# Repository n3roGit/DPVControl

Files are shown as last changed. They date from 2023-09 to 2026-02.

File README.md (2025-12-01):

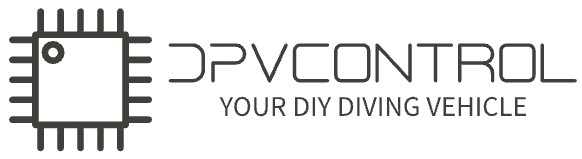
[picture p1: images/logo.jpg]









# THE PROJECT
In this GitHub project, the aim is to build and operate a DPV (Dive Propulsion Vehicle) using standard components. In my case, I will breathe new life into an old Aquazepp. The motor I'm using is a common 2000-watt scooter motor, controlled by a VESC (Vedder Electronic Speed Controller). The entire system is controlled through Reed switches activated by magnets with a Bowden cable.

See the full build process in my [blog](https://3o0.de/gu0).

I would greatly appreciate support for my project. Every $ contributes to enhancing the project.

<a href="https://www.paypal.com/cgi-bin/webscr?cmd=_s-xclick&hosted_button_id=6ZFSVPZWLLAMC">
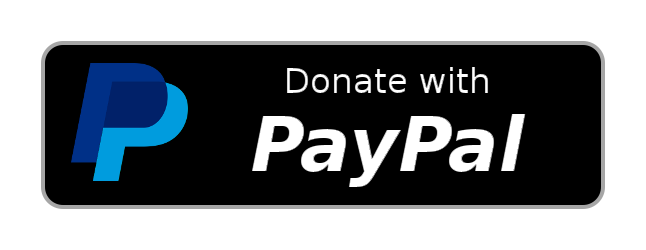
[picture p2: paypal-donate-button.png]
Donate with PayPal
  
</a>

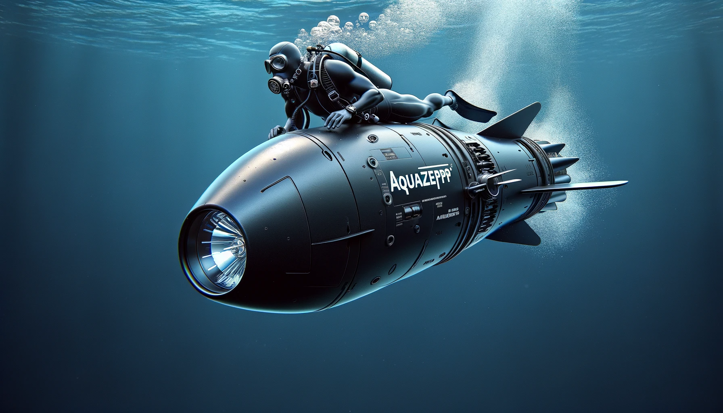
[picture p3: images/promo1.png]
PROMO


# Development

## PlatformIO with VS Code
This project uses **PlatformIO** for development, which provides better dependency management and build system compared to the Arduino IDE.

### Setup Instructions

1. **Install VS Code**: Download from [code.visualstudio.com](https://code.visualstudio.com/)

2. **Install PlatformIO Extension**: 
   - Open VS Code
   - Go to Extensions (Ctrl+Shift+X)
   - Search for "PlatformIO IDE" and install it

3. **Open Project**:
   - Clone this repository
   - Open the project folder in VS Code
   - PlatformIO will automatically detect the `platformio.ini` file

4. **Build and Upload**:
   - Use the PlatformIO toolbar at the bottom of VS Code
   - Click "Build" (✓) to compile
   - Click "Upload" (→) to flash to ESP32
   - Click "Serial Monitor" to view debug output

### Pre-commit Hook for Automated Testing

To ensure code quality, a pre-commit hook is provided that automatically runs all tests before each commit. This prevents commits if any test fails.

**Installation:**
1. Make sure the file `pre-commit.ps1` is located in the project root (it is versioned).
2. In the `.git/hooks/` directory, create a file named `pre-commit.bat` with the following content:
   ```bat
   @echo off
   REM pre-commit hook: runs all PlatformIO tests and prevents commit on failure
   echo Running all tests before commit...
   python -m platformio test -e native
   if errorlevel 1 (
       echo.
       echo ERROR: Some tests failed. Commit aborted!
       exit /b 1
   )
   echo All tests passed. Commit allowed.
   exit /b 0
   ```
3. From now on, all tests will be run automatically before each commit. The commit will be aborted if any test fails.

> **Note:**
> The pre-commit hook only works if you commit from the terminal (CMD). Many GUIs like GitHub Desktop or VSCode-Git do not execute local hooks or do not support batch/shell scripts as hooks.

### Dependencies
All required libraries are automatically managed through `platformio.ini`:
- ArduinoJson, ESP32Servo, OneWire, DallasTemperature
- DHT sensor library, Adafruit NeoPixel
- VescUart, ClickButton, Uptime Library

No manual library installation required!

### Makefile Usage

For a quick command-line workflow, a `Makefile` is provided.  The most common
tasks can be run with:

```bash
make install   # install PlatformIO and Python dependencies
make test      # run unit tests
make build     # build the firmware
make upload    # upload firmware to the ESP32
```

Use `make` without arguments to list all available targets.

# API Documentation

The DPV Control system provides a comprehensive REST API for system monitoring, data retrieval, and configuration management.

📖 **[View API Specification](./api-specification.yaml)** - Complete OpenAPI 3.0 documentation

**Quick Links:**
- **Interactive Documentation:** Open `api-specification.yaml` in [Swagger Editor](https://editor.swagger.io/) or VS Code with OpenAPI extension
- **Base URL:** `http://4.3.2.1` (when connected to DPV WiFi)
- **Format:** JSON REST API

**Available Endpoints:**
- `GET /api/status` - Real-time system status and sensor readings
- `GET /api/data` - Historical sensor data with filtering options
- `GET /api/trip-log` - Complete trip log download
- `GET /api/settings` - Current device configuration
- `POST /api/settings` - Update device settings
- `POST /api/settings/restore` - Restore default settings

**Features:**
- Real-time monitoring of all sensor data
- Historical data retrieval with configurable time ranges
- Complete settings management with validation
- Trip log export functionality
- Session-based data filtering

# Click Codes

| Switch 1 | Switch 2 | Function |
|:---:|:---:|:---:|
| Hold | Hold | Turn motor ON |
| Hold | | Turn motor ON |
| | Hold | Turn motor ON |
| 1 Click  | 1 Click  |  cruise control |
| 1 Click  | | |
| | 1 Click  | |
| 2 Clicks | 2 Clicks | Boost Mode |
| 2 Clicks | | Reactivate |
| | 2 Clicks | Reactivate |
| 2 Clicks | 	 | Stepwise slower |
| | 2 Clicks | Stepwise faster |
| 3 Clicks | 3 Clicks | PowerBank ON/OFF|
| 3 Clicks | | Short light flash |
| | 3 Clicks | Light Level 1, 2, 3, 4, OFF |
| 4 Clicks | 4 Clicks | toggle reverse drive mode (fixed low speed) |
| 4 Clicks | | beep Battery level |
| | 4 Clicks |  |

# Beep Codes
1 = short beep
2= long beep
| Beep | Function | 
|:---:|:---:|
| 12121212 | Leak warning |
|1|still in standby|
|11|going to standby or wake up from standby|
|2|10% battery left|
|22|20% battery left|
|222|30% battery left|
|n*2| Get n beep for every 10% left in battery (beep Battery level)|
|1| once after boot|
|111|No speedup because overloaded|
|1|speed steps exeeded|
|12|Overloaded for too long. Lowering speed.|
|21|No longer overloaded|
|111222111|SOS - Long time without any action. The lamp is also activated with the same code|

# Pinout
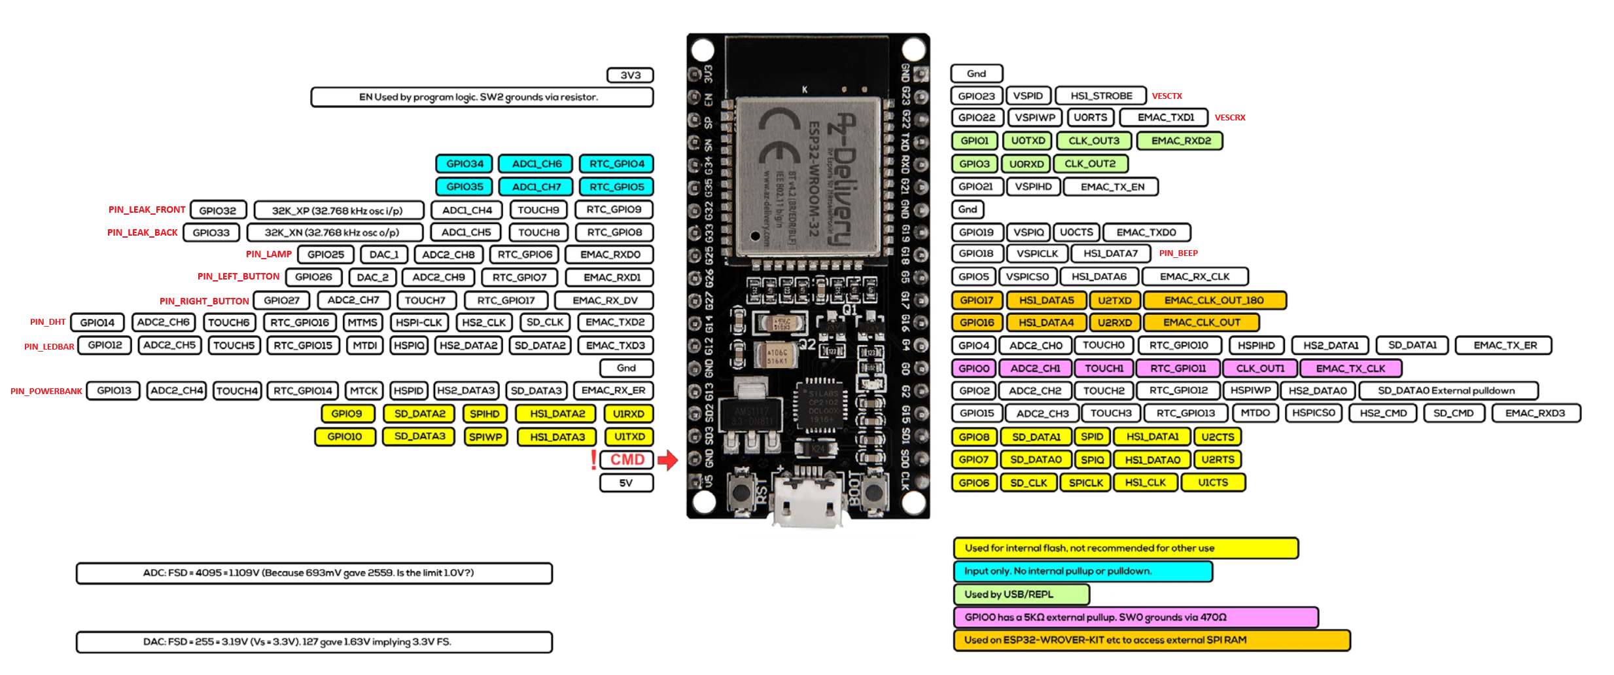
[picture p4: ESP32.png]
ESP32


# Logic
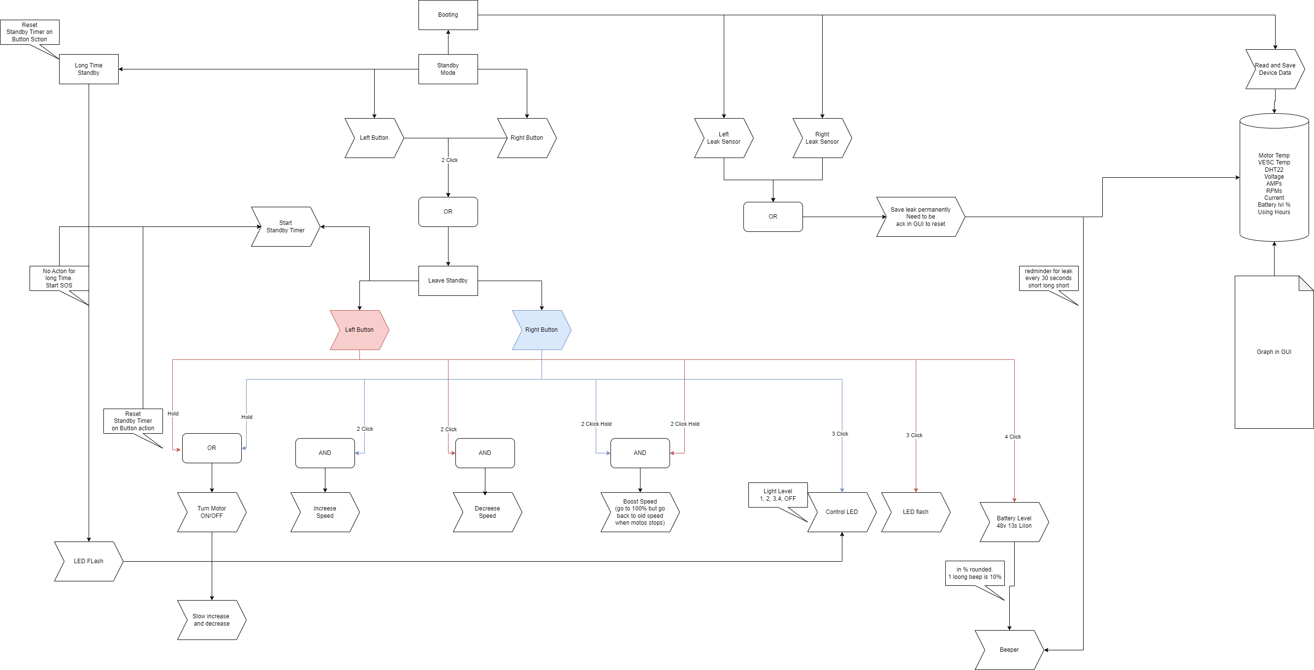
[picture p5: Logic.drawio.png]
logic


# GUI
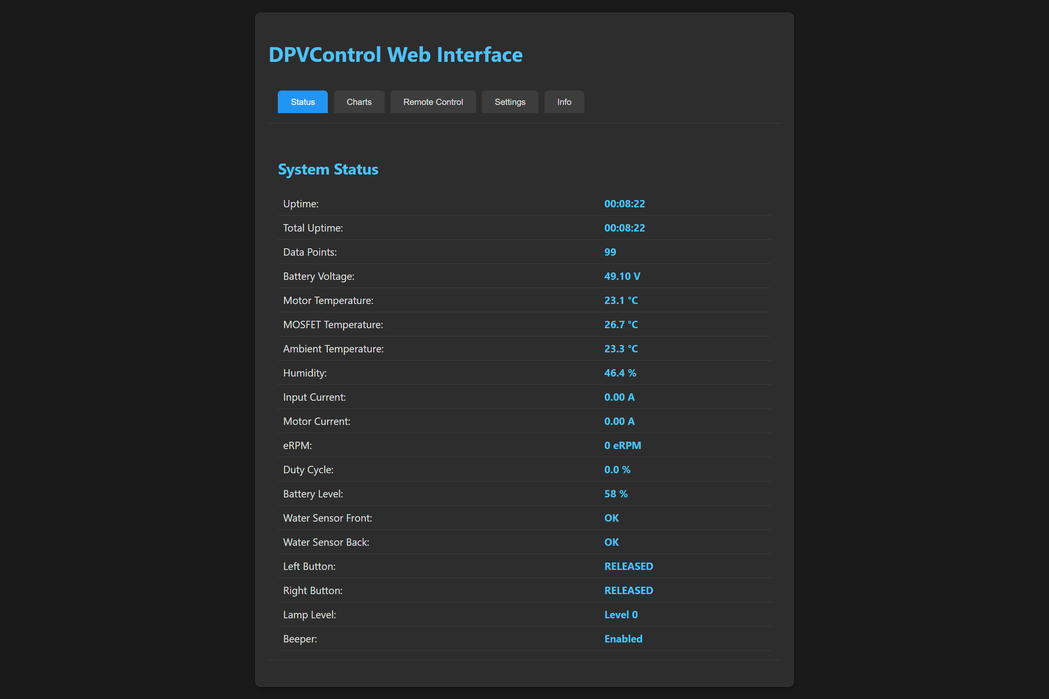
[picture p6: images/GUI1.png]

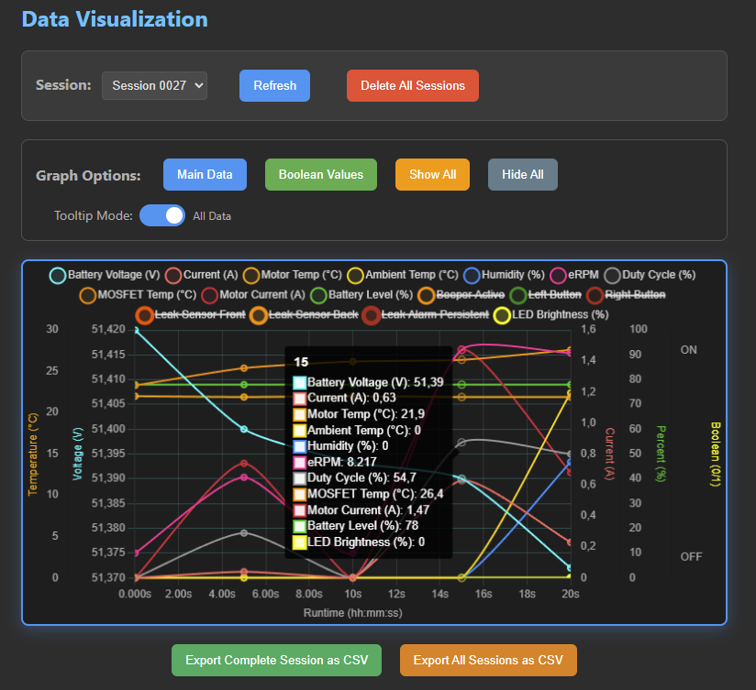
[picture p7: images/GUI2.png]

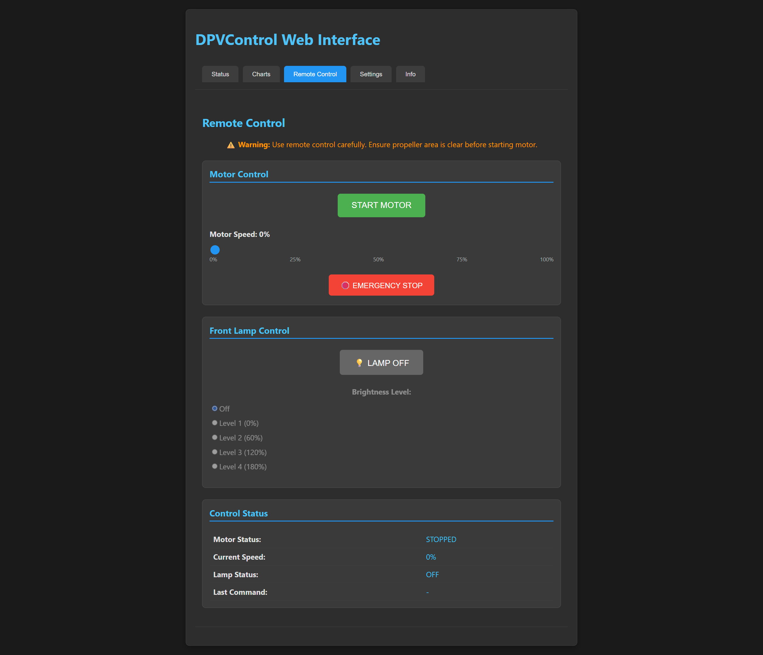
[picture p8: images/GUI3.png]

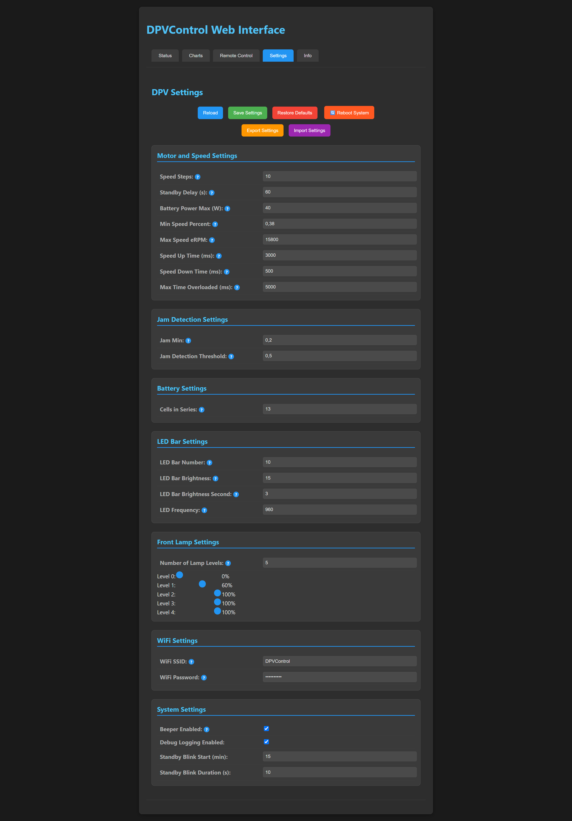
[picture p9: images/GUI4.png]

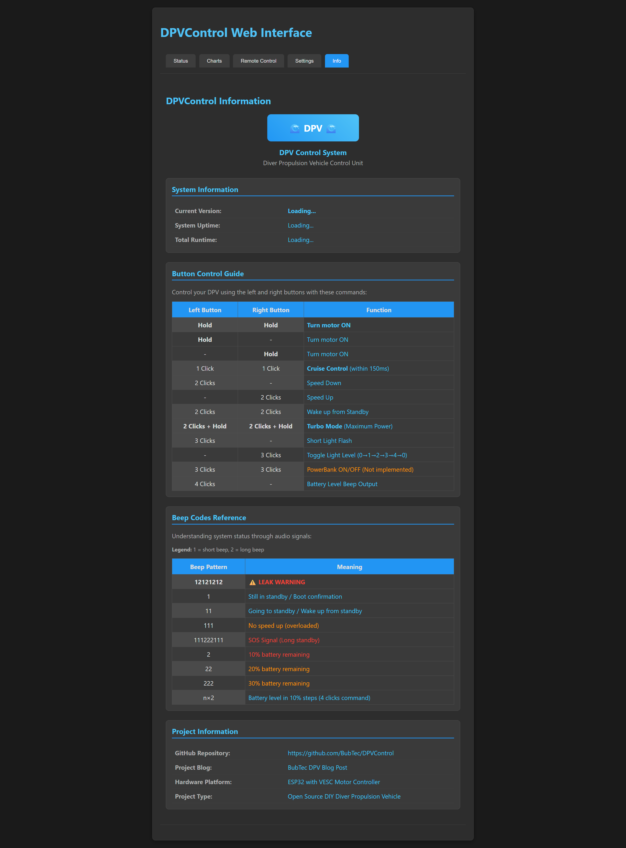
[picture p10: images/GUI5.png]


# Hardware Updates
| Change                                        |
|-----------------------------------------------|
| Handle replaced with POM tube                 |
| Caveline replaced by thin V4A steel cable    |
| Stator integrated to eliminate lateral torque|
| Tow/haul line attached at the top            |
| Impact protection fitted over the magnetic switches|

# Videos
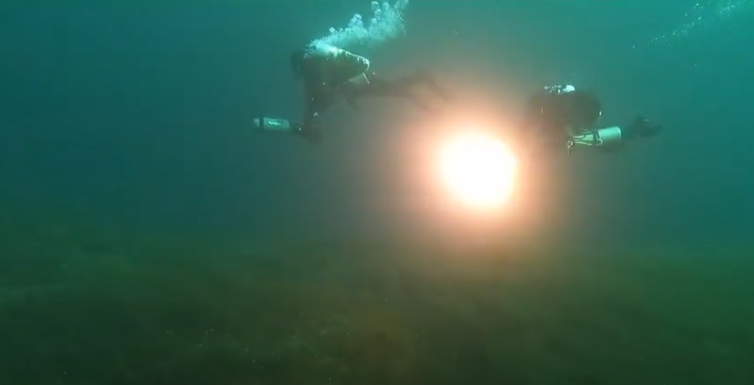
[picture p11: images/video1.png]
[](https://youtu.be/6myfqZKiGTU "Aquazepp first ride")
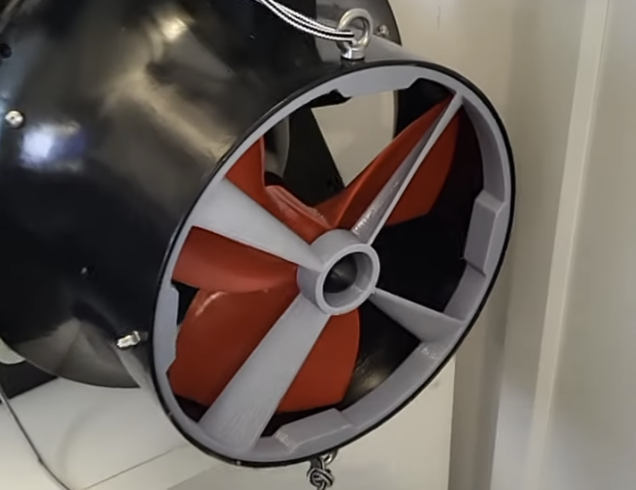
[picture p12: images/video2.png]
[](https://youtube.com/shorts/ZGKomkWQHeM "Aquazepp Stator")
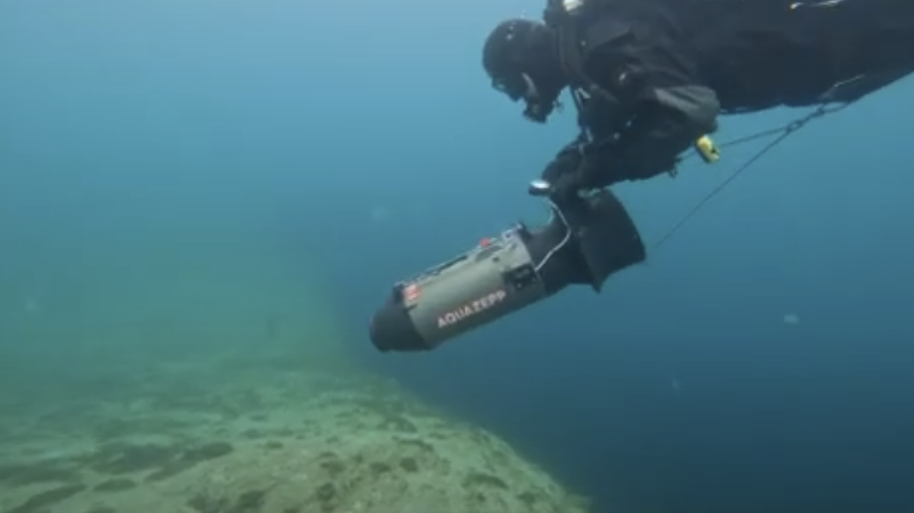
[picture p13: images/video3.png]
[](https://www.youtube.com/watch?v=6m43nQFAH6o "Full speed drive")

# Build Process
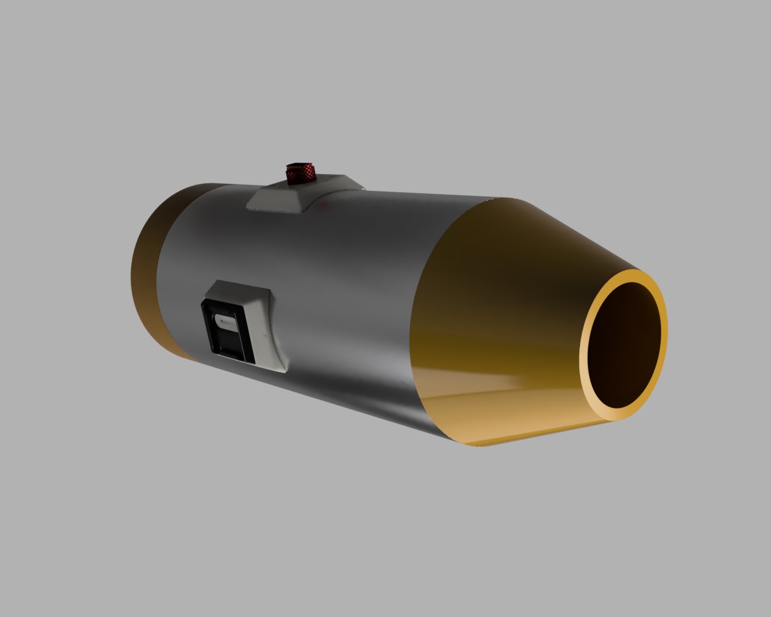
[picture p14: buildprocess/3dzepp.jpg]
Build

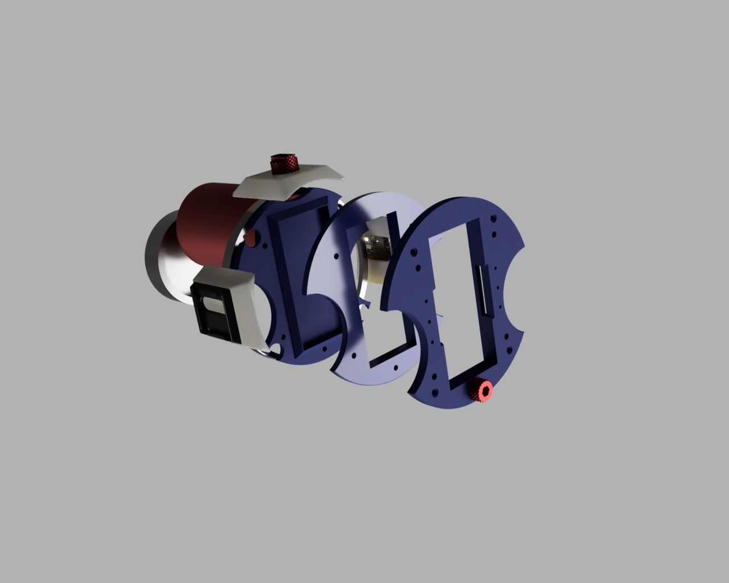
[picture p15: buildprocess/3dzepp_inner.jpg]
Build

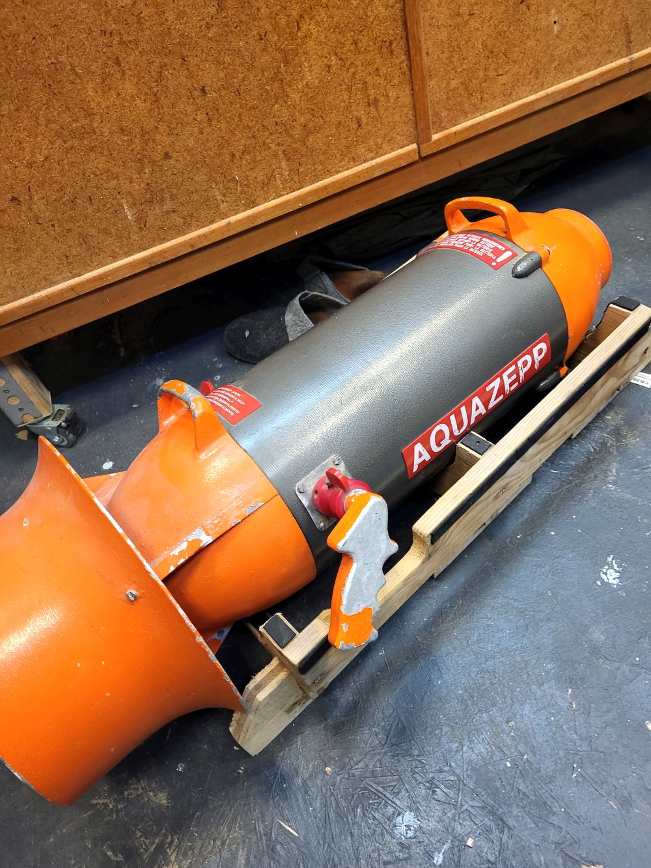
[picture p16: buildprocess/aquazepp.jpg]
Build

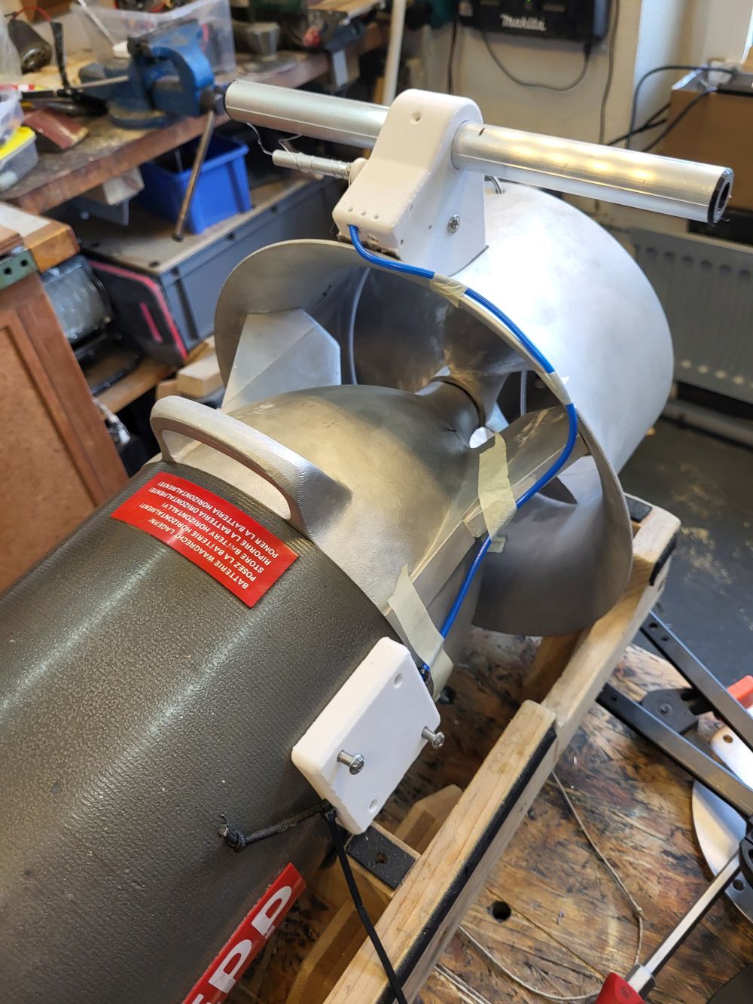
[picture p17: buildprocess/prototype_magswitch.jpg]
Build

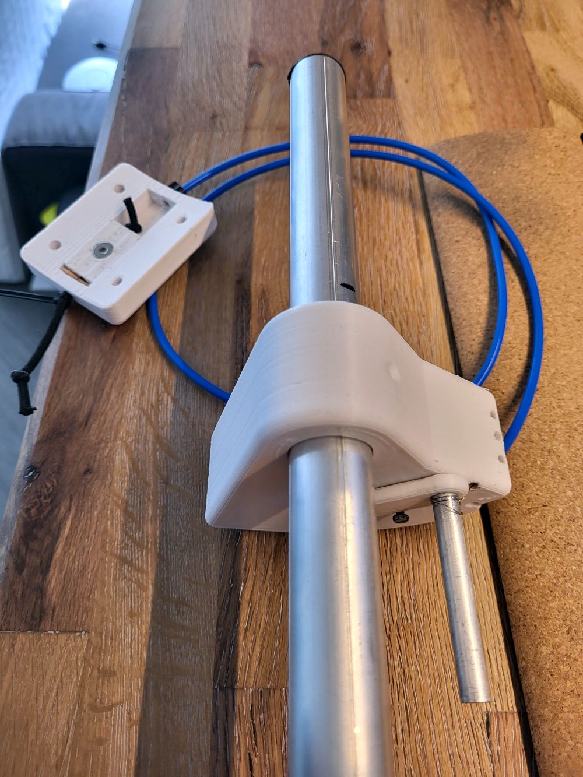
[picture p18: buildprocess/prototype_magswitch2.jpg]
Build

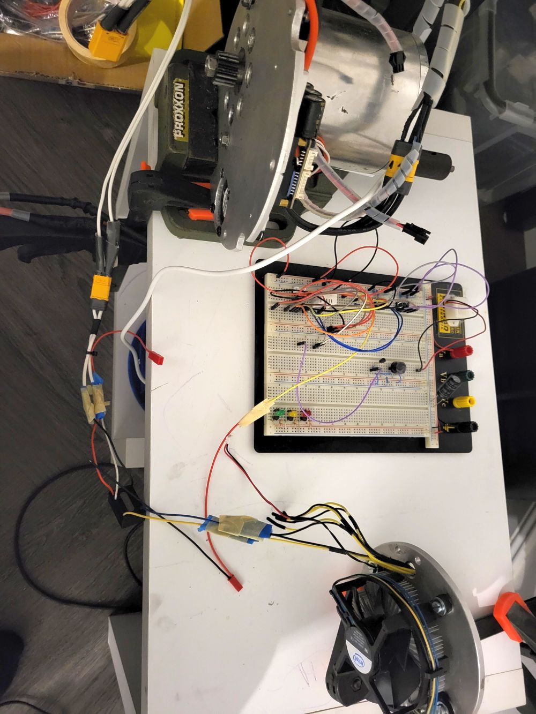
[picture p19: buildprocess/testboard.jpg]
Build

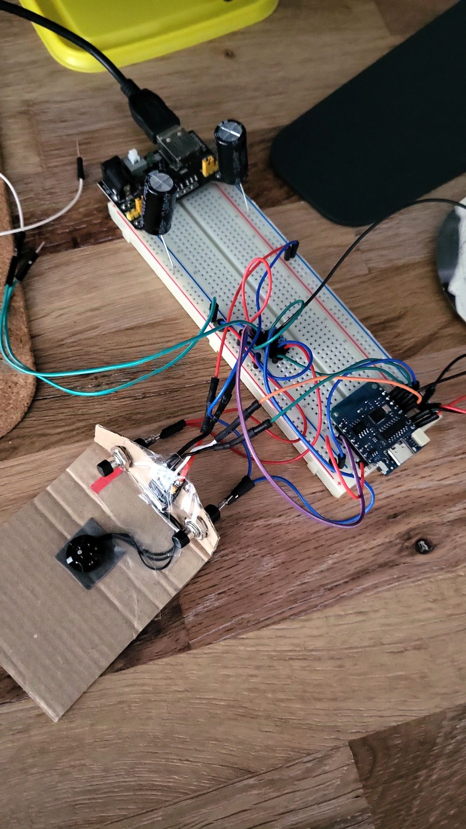
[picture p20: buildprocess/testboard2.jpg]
Build

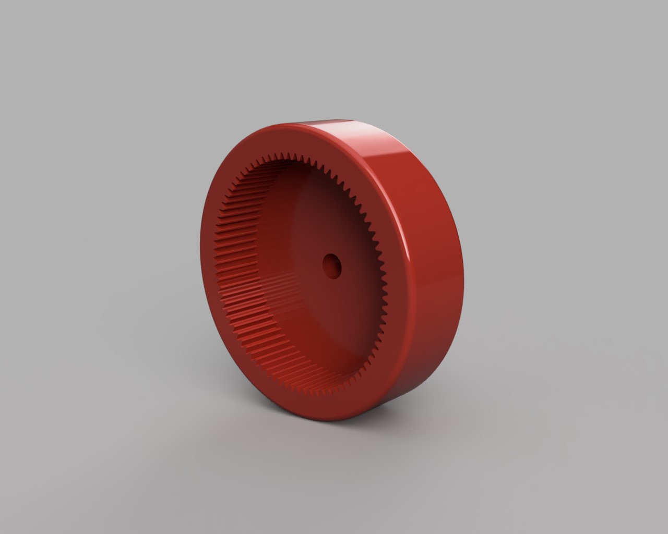
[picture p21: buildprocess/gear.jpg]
Build

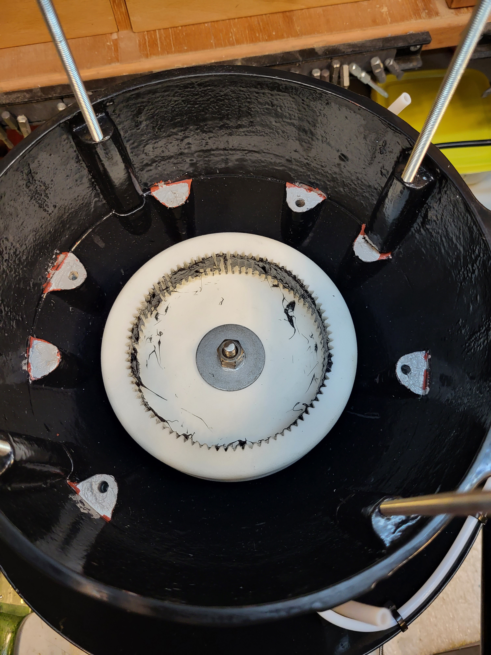
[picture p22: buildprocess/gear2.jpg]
Build

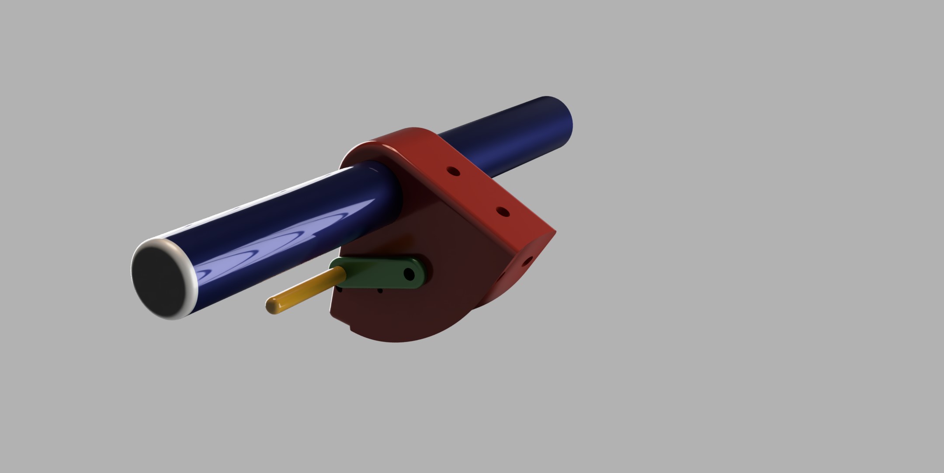
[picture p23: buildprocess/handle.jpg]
Build

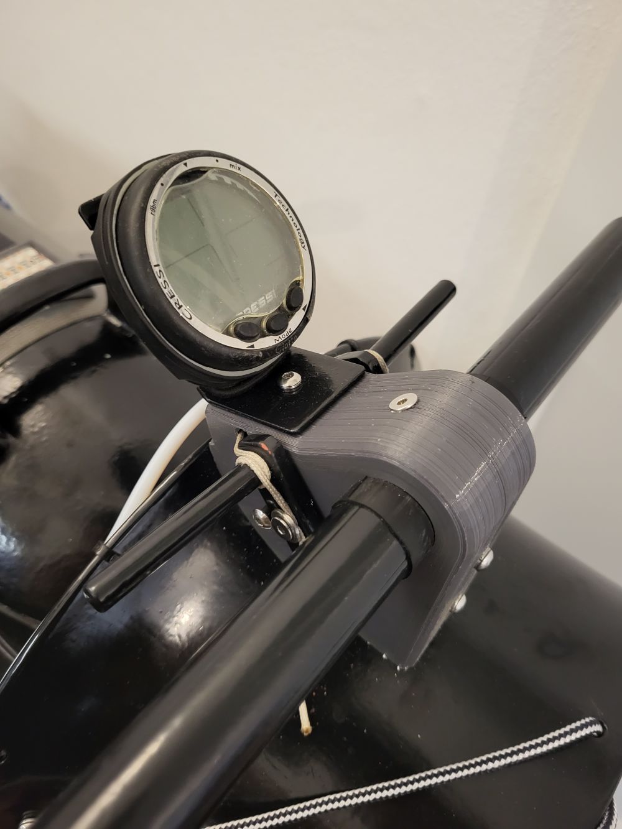
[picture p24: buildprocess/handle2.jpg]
Build

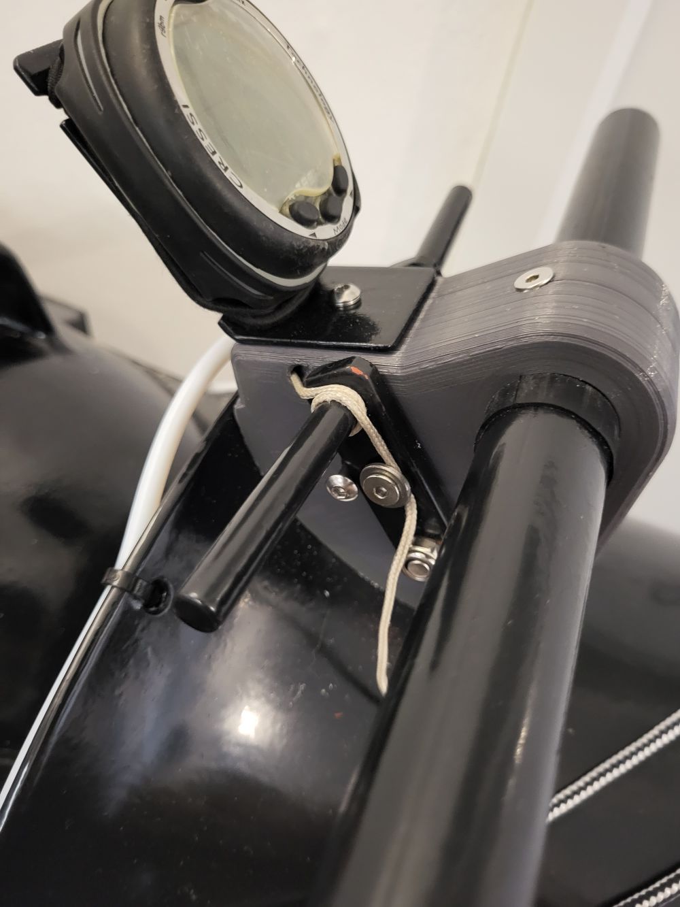
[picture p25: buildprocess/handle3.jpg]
Build

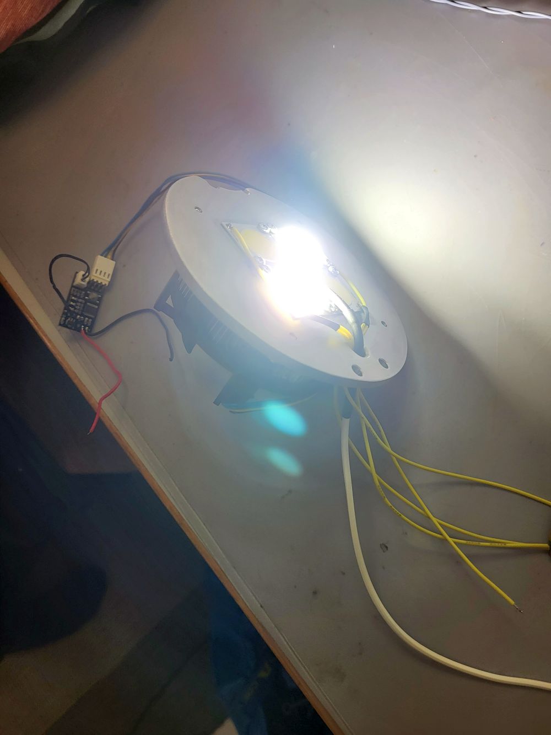
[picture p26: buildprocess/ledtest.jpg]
Build

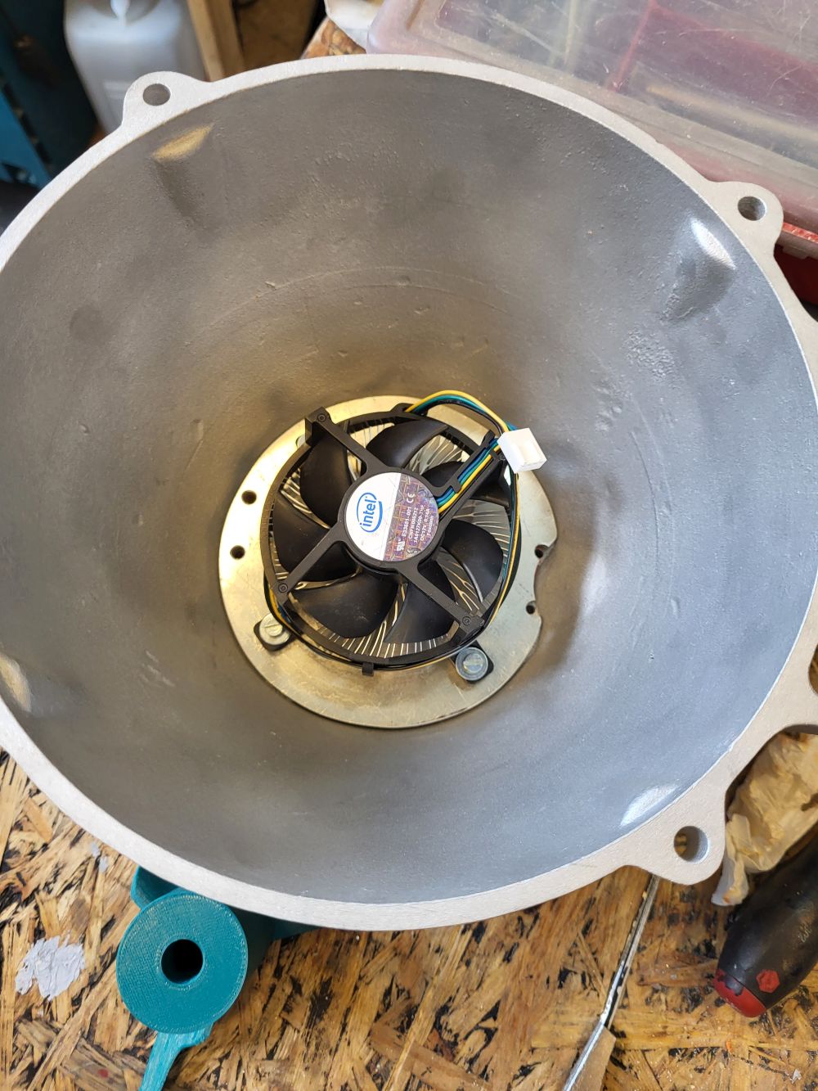
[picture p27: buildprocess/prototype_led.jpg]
Build

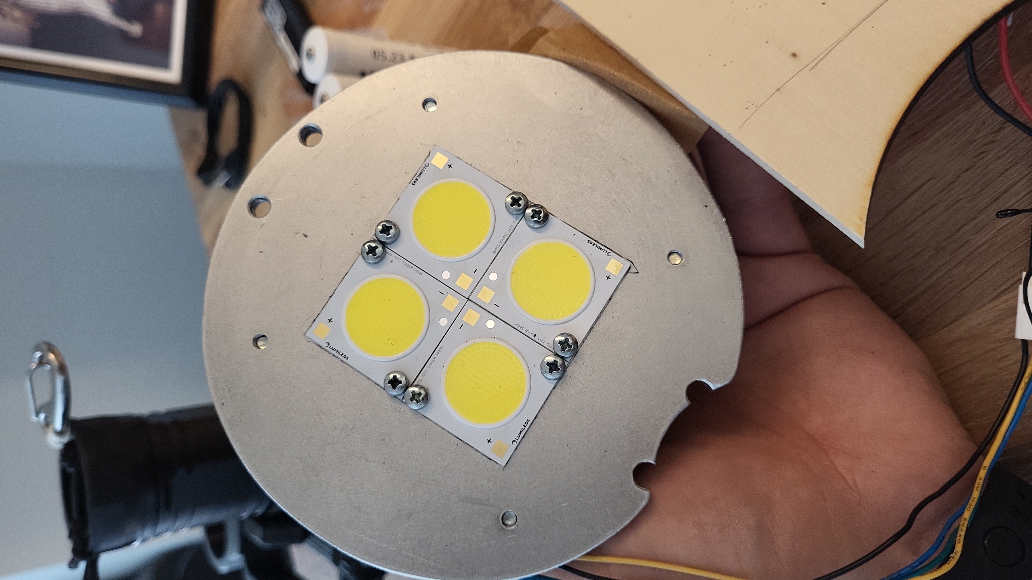
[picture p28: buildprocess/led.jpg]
Build

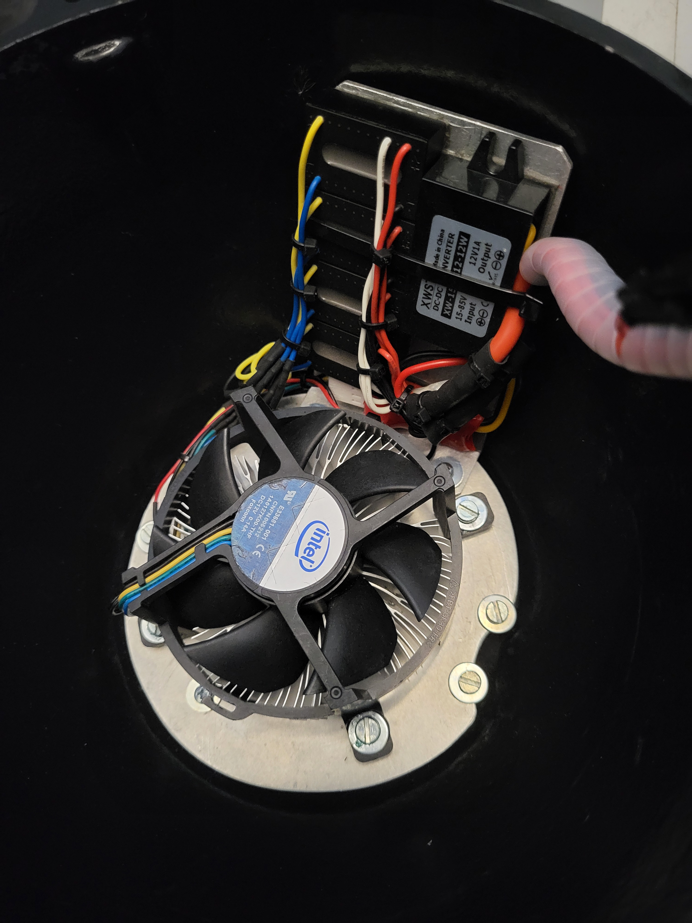
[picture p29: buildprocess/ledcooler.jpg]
Build

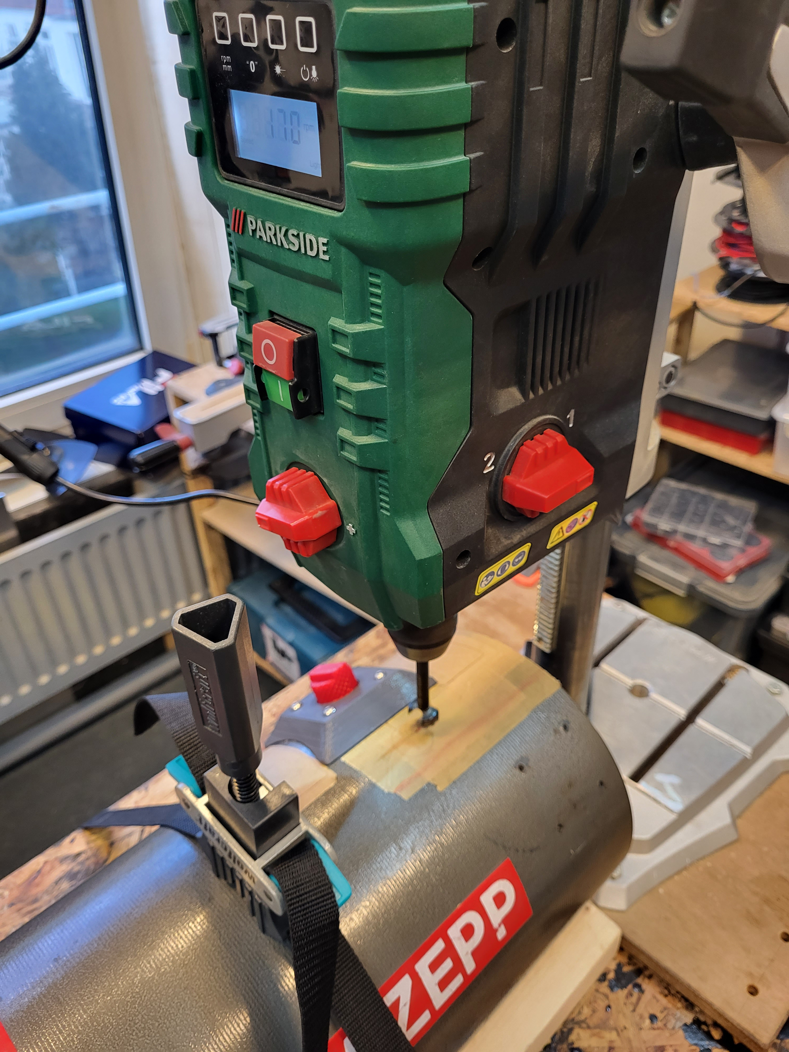
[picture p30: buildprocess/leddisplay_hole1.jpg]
Build

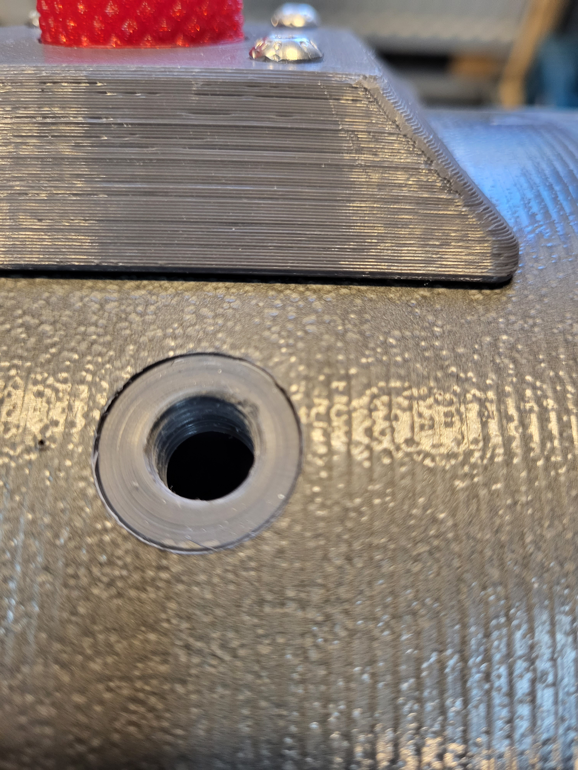
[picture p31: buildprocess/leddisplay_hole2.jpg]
Build

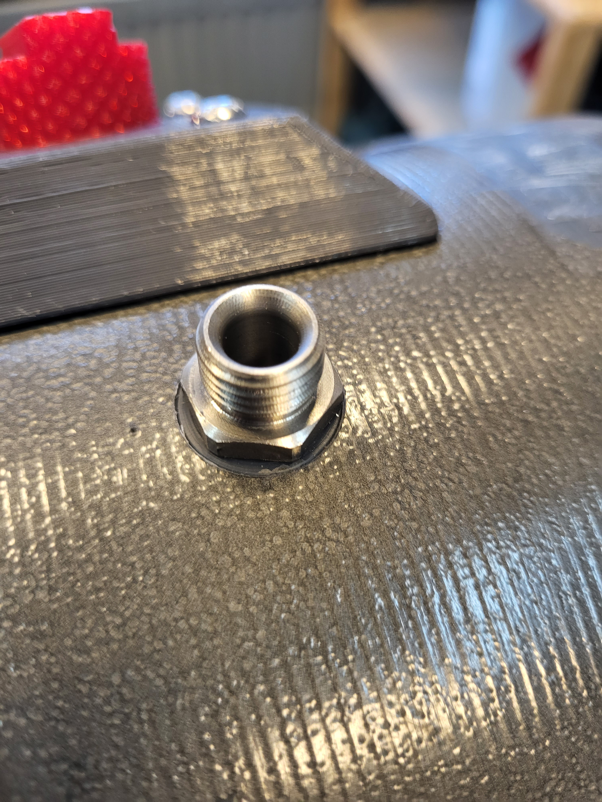
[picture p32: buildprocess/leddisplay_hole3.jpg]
Build

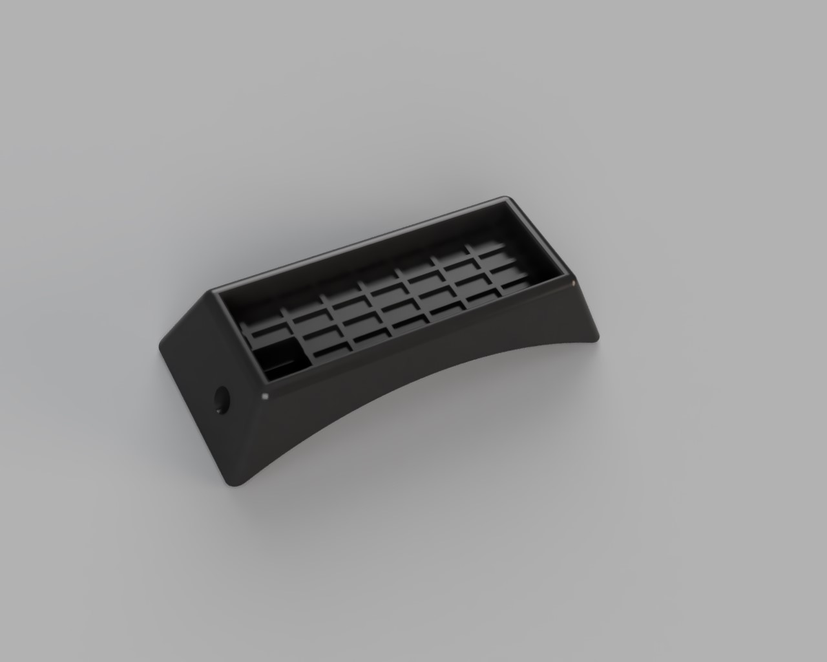
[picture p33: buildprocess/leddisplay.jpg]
Build

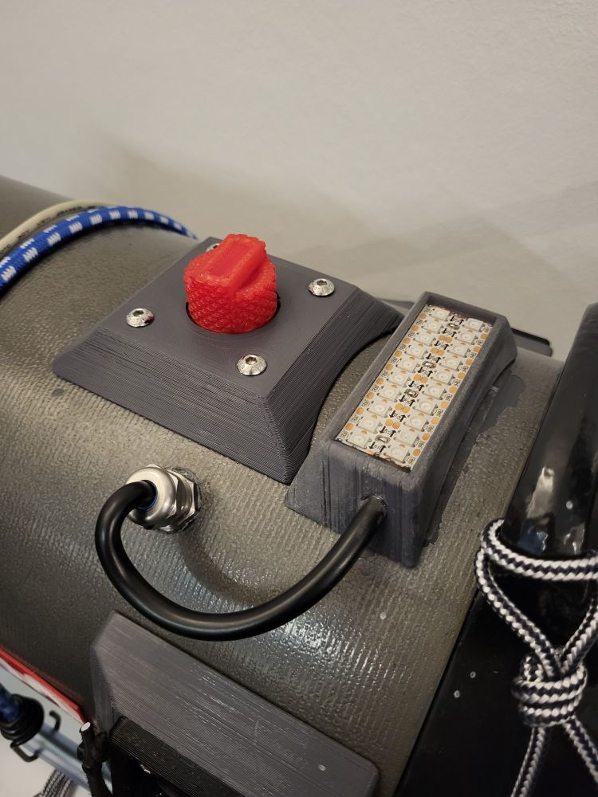
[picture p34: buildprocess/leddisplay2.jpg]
Build

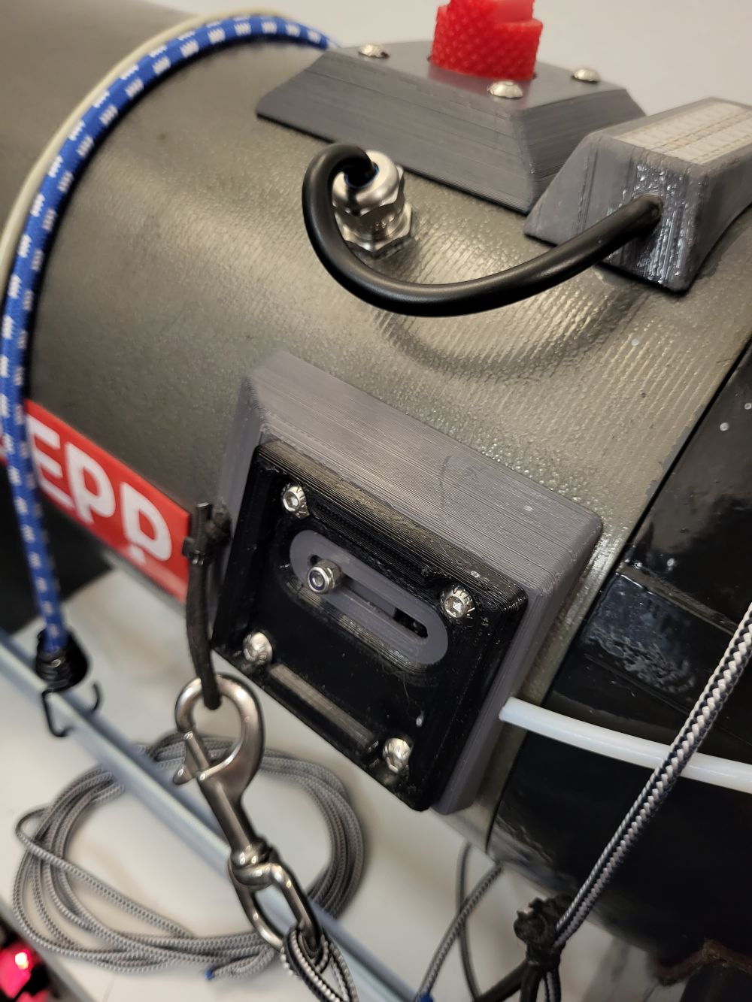
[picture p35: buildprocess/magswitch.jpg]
Build

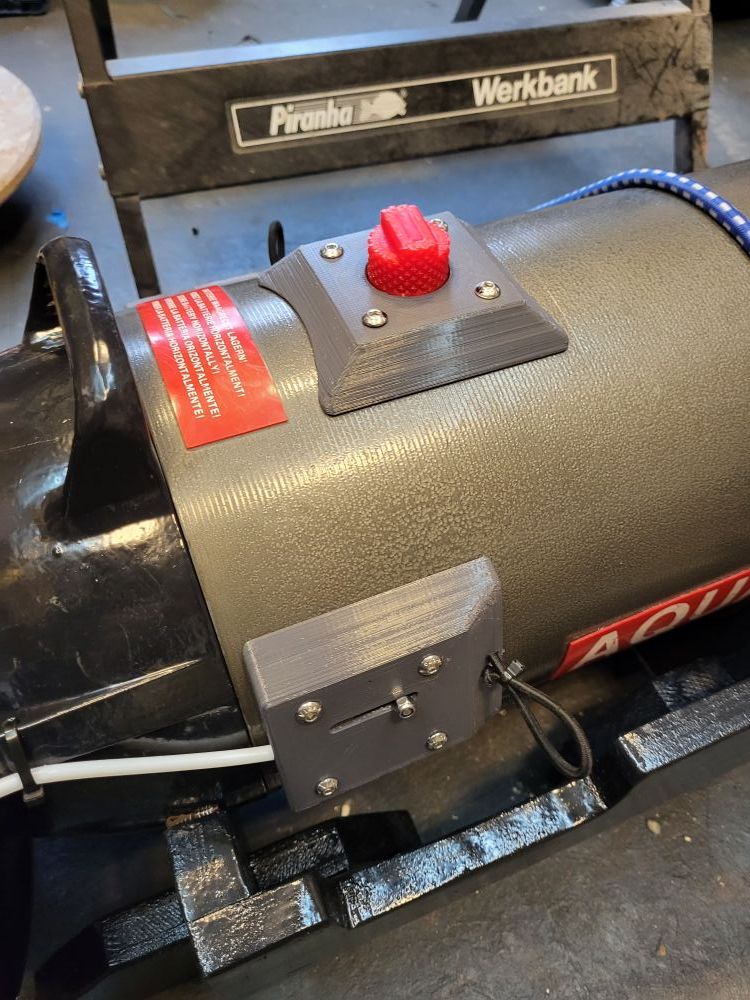
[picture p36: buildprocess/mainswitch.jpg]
Build

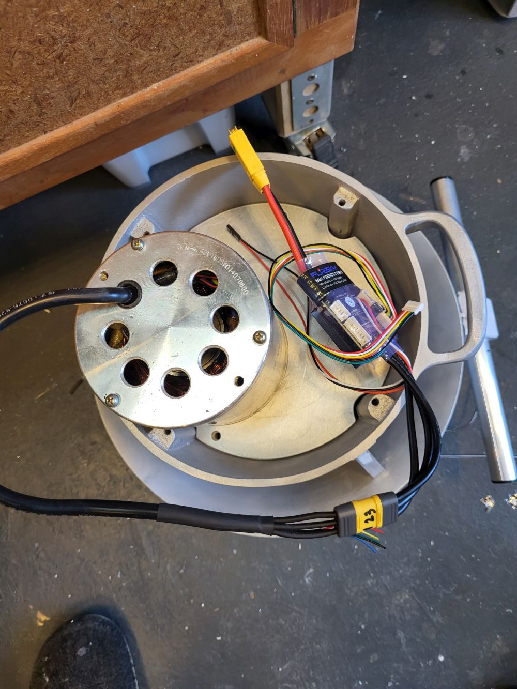
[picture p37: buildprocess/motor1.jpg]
Build

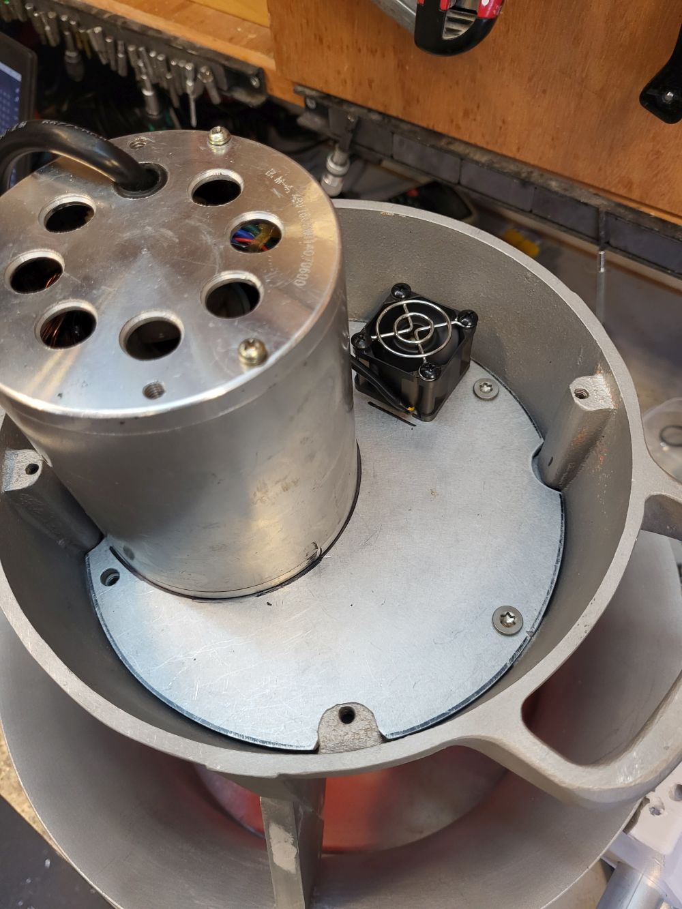
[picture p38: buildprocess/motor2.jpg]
Build

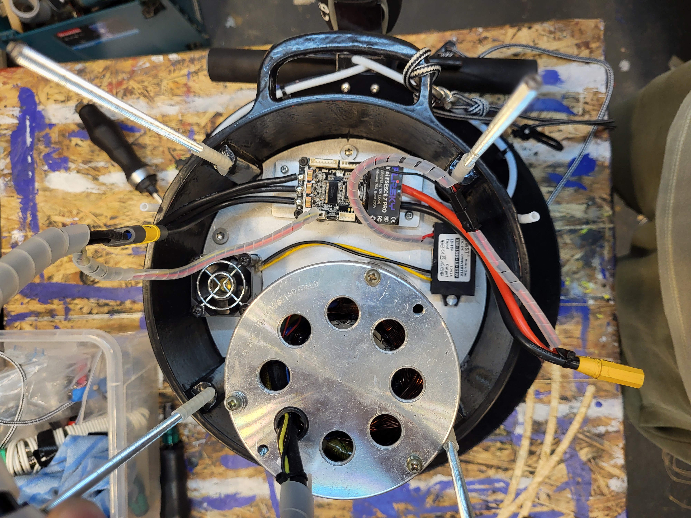
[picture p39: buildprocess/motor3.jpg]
Build

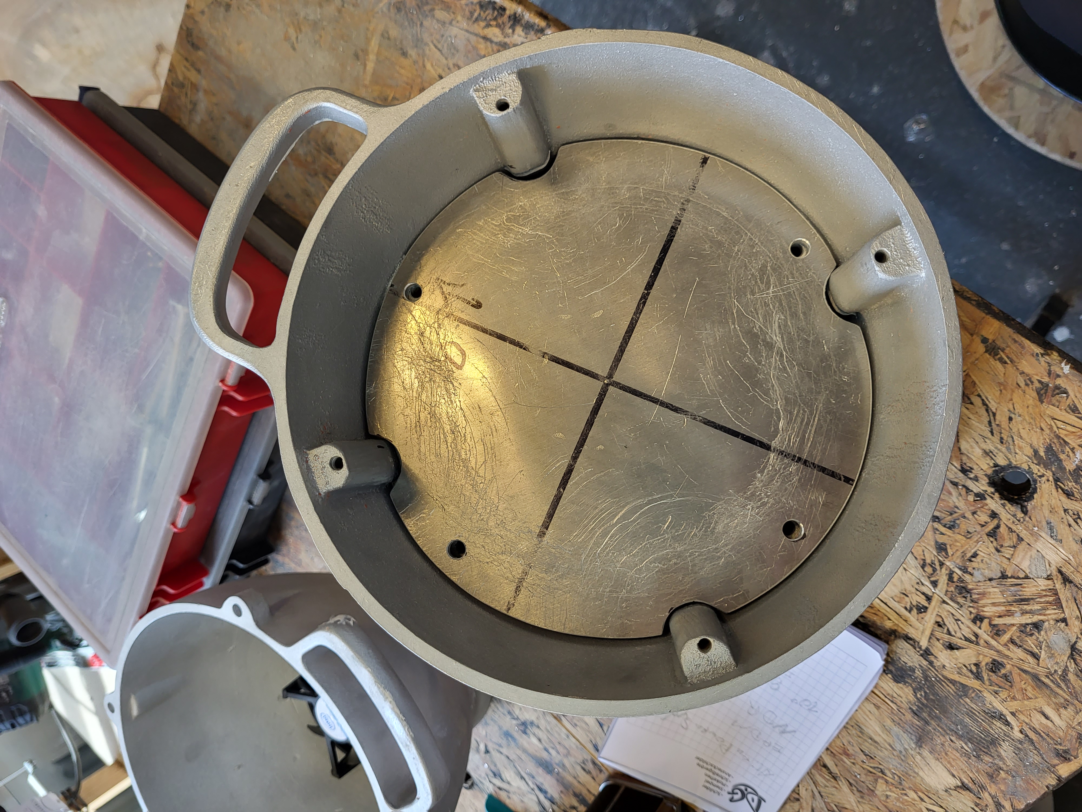
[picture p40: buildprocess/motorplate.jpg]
Build

Build
Build
Build
Build
Build
Build
Build
Build
Build
Build
Build
Build

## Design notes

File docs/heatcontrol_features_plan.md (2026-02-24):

# HeatControl-Features in DPVControl übernehmen

> **GitHub Issues:** Alle Features sind als Issues angelegt. Siehe:
> [#81](https://github.com/BubTec/DPVControl/issues/81) Verzögerter Neustart |
> [#82](https://github.com/BubTec/DPVControl/issues/82) Cache-Control-Header |
> [#83](https://github.com/BubTec/DPVControl/issues/83) Serial Log |
> [#84](https://github.com/BubTec/DPVControl/issues/84) Dynamisches Log-Level |
> [#85](https://github.com/BubTec/DPVControl/issues/85) Erweiterte Captive-URLs |
> [#86](https://github.com/BubTec/DPVControl/issues/86) Serial-Log-Panel |
> [#87](https://github.com/BubTec/DPVControl/issues/87) Client-Zugriffskontrolle |
> [#88](https://github.com/BubTec/DPVControl/issues/88) i18n DE/EN |
> [#90](https://github.com/BubTec/DPVControl/issues/90) HeimNetz + Auto AP |
> [#89](https://github.com/BubTec/DPVControl/issues/89) OTA Update

---

## Übersicht beider Projekte

| Aspekt | HeatControl | DPVControl |
| --- | --- | --- |
| **Plattform** | ESP32-C3 | ESP32 (esp32dev) |
| **Webserver** | AsyncWebServer (ESPAsyncWebServer) | Synchroner WebServer (WiFiServer) |
| **WiFi** | WIFI_AP_STA (AP + HeimNetz/STA) | WIFI_AP (nur AP) |
| **Storage** | EEPROM | LittleFS (JSON) |
| **OTA** | `/update` mit multipart upload | Kein OTA |
| **Serial Log** | Rolling buffer + `/logs` Endpoint  | Nur Serial.print, kein Buffer |
| **AP-Abschaltung** | Auto-Off nach X Min ohne STA | Nicht vorhanden |

---

## 1. Verzögerter Neustart (scheduleRestart) – Risiko 1/10 → [#81](https://github.com/BubTec/DPVControl/issues/81)

**HeatControl:** `scheduleRestart(delayMs)` – Neustart erst nach X ms, damit HTTP-Response vollständig gesendet wird.

**DPVControl:** Sofortiger `ESP.restart()` nach `/api/reboot`; Response könnte abgeschnitten werden.

**Übernahme:** Reboot um 1–2 Sekunden verzögern; in der Zwischenzeit weiterhin Requests bedienen. Globale Variablen `volatile bool restartScheduled`, `volatile unsigned long restartAtMs` – werden vom Webserver (Core 0) gesetzt, von loop() (Core 1) gelesen.

**Risiko: 1/10** – Sehr gering. Verbessert Zuverlässigkeit der Reboot-Response.

---

## 2. Cache-Control-Header – Risiko 1/10 → [#82](https://github.com/BubTec/DPVControl/issues/82)

**HeatControl:** `DefaultHeaders::Instance().addHeader("Cache-Control", "no-cache, no-store, must-revalidate")` für alle Responses.

**DPVControl:** Teilweise Cache-Header; nicht einheitlich.

**Übernahme:** Bei allen API-Responses und HTML-Seiten konsistent `Cache-Control: no-cache` setzen.

**Risiko: 1/10** – Sehr gering. Reine Header-Ergänzung.

---

## 3. Serial Log – Risiko 2/10 → [#83](https://github.com/BubTec/DPVControl/issues/83)

**HeatControl:** Rolling-Buffer (`serialLogBuffer[12001]`), `appendLineToRollingBuffer()` in logic_helpers.cpp, alle `logLine()`/`logf()` schreiben zusätzlich in den Buffer, Endpoint `/logs` liefert Buffer als text/plain.

**DPVControl:** [log.cpp](../src/log.cpp) nutzt nur `Serial.print()`; kein Buffer, kein Log-Endpoint.

**Übernahme:**

- Rolling-Buffer-Funktion portieren (ohne HeatControl-spezifische Abhängigkeiten) oder vereinfachte Variante in DPVControl implementieren
- **Mutex** für Buffer-Zugriff (log() wird von Core 0 und Core 1 aufgerufen – webserver, vesc, datalog, main loop)
- `log()` in [log.cpp](../src/log.cpp) erweitern: zusätzlich in Buffer schreiben
- Neuer API-Endpoint `/api/logs` (GET) – liefert Buffer als text/plain
- [api-specification.yaml](../api-specification.yaml) und Web-UI anpassen (z.B. Log-Tab oder -Modal)

**Risiko: 2/10** – Gering. Mutex erforderlich wegen Multi-Core-Zugriff.

---

## 4. Dynamisches Log-Level (setLogLevel) – Risiko 2/10 → [#84](https://github.com/BubTec/DPVControl/issues/84)

**HeatControl:** Log-Level (Error/Info/Debug) per POST `/setLogLevel` umschaltbar, persistent in EEPROM.

**DPVControl:** `debugLoggingEnabled` (boolean) in Settings, nur über Settings-API änderbar.

**Übernahme:** Entweder `debugLoggingEnabled` beibehalten oder dreistufiges Log-Level einführen. Neuer Endpoint `/api/log-level` (GET/POST) oder Erweiterung von Settings.

**Web-UI:** Dropdown/Select (Error/Info/Debug) in Settings oder im Serial-Log-Panel (Feature 6); Speichern-Button.

**Risiko: 2/10** – Gering. Bestehende Logik anpassen; Debug-Logging könnte Performance beeinträchtigen.

---

## 5. Erweiterte Captive-Portal-URLs – Risiko 2/10 → [#85](https://github.com/BubTec/DPVControl/issues/85)

**HeatControl:** Zusätzliche Handler: `/gen_204`, `/fwlink`, `/library/test/success.html`, `/connecttest.txt.gz`, etc. Plus `CaptiveRequestHandler` für unbekannte Hosts.

**DPVControl:** Hat bereits `/generate_204`, `/ncsi.txt`, `/hotspot-detect.html`, etc. Fehlt u.a. `/gen_204`, `/fwlink`, einige Varianten.

**Übernahme:** Fehlende Pfade ergänzen; ggf. Host-basierte Redirect-Logik nachbilden.

**Risiko: 2/10** – Gering. Nur zusätzliche Redirect-Pfade; Verbesserung der Captive-Portal-Erkennung.

---

## 6. Serial-Log-Panel in der Web-UI – Risiko 2/10 → [#86](https://github.com/BubTec/DPVControl/issues/86)

**HeatControl:** Eigenes Panel mit Log-Level-Dropdown, Auto-Scroll, periodischem Abruf von `/logs`.

**DPVControl:** Kein Log-Panel.

**Übernahme:** Nach Implementierung von Serial Log (Feature 3) ein Log-Panel/Modal in der Web-UI einbauen – analog HeatControl. **Abhängigkeit:** Feature 3 muss zuerst implementiert sein.

**Web-UI:** Log-Anzeige (pre/textarea), Log-Level-Dropdown, Auto-Scroll, Aktualisieren-Button.

**Risiko: 2/10** – Gering. Abhängig von Feature 3; nur Frontend.

---

## 7. Client-Zugriffskontrolle (isAllowedWebClient) – Risiko 3/10 → [#87](https://github.com/BubTec/DPVControl/issues/87)

**HeatControl:** Schreibende Endpoints (POST/PUT) prüfen Client-IP. Erlaubt: 4.3.2.x (AP), 10.x, 172.16–31.x, 192.168.x. Andere IPs erhalten 403 Forbidden.

**DPVControl:** Keine Zugriffskontrolle – jeder im AP kann alle Endpoints nutzen.

**Übernahme:** Vor schreibenden API-Handlern Client-IP prüfen; bei ungültiger IP 403 zurückgeben. DPVControl nutzt `client.remoteIP()` – analog implementierbar.

**Risiko: 3/10** – Gering. Nur zusätzliche Prüfung; falsche Konfiguration könnte legitime Clients blockieren.

---

## 8. Mehrsprachigkeit (i18n DE/EN) – Risiko 4/10 → [#88](https://github.com/BubTec/DPVControl/issues/88)

**HeatControl:** Vollständige Übersetzung in der Web-UI (data-i18n, `t()`-Funktion, langToggleBtn). DE/EN wechselbar.

**DPVControl:** Web-UI nur auf Englisch (bzw. gemischt).

**Übernahme:** i18n-Objekt mit Keys, `t(key)`-Funktion, data-i18n-Attribute, Sprachumschalter. Relativ viel UI-Arbeit.

**Web-UI:** Sprachumschalter-Button (DE/EN); alle Texte mit data-i18n versehen.

**Risiko: 4/10** – Mittel. Kein Funktionsrisiko, aber viele Strings; fehlende Keys zeigen Key-Namen.

---

## 9. HeimNetz + Auto AP Abschaltung – Risiko 5/10 → [#90](https://github.com/BubTec/DPVControl/issues/90)

**HeatControl:**

- WIFI_AP_STA: AP und STA gleichzeitig
- STA verbindet sich mit HeimNetz (activeSsid/activePassword)
- Wenn STA verbunden und AP nicht manuell aktiviert → AP wird abgeschaltet
- `apAutoOffMinutes`: Wenn nach X Minuten kein STA → AP aus, WiFi komplett aus

**DPVControl:**

- Nur AP; `wifiSSID`/`wifiPassword` sind AP-Credentials
- Keine STA-Verbindung, kein Auto-Off

**Übernahme:**

- **Neue Settings:** `staSSID`, `staPassword` (HeimNetz), `apAutoOffMinutes` (0 = deaktiviert)
- **AP-Credentials:** Bleiben `wifiSSID`/`wifiPassword` (oder umbenennen zu `apSSID`/`apPassword` für Klarheit)
- **WiFi-Start:** `WiFi.mode(WIFI_AP_STA)` wenn STA-Credentials gesetzt, sonst weiterhin nur AP
- **STA-Connect:** `WiFi.begin(staSSID, staPassword)` im Setup
- **Loop-Logik (wie HeatControl):**
  - Wenn STA verbunden und AP nicht manuell aktiviert → `WiFi.softAPdisconnect()`, `WiFi.mode(WIFI_STA)` → **primär über HeimNetz erreichbar**
  - Wenn `apAutoOffMinutes > 0` und kein STA nach Timeout → AP aus, ggf. WiFi komplett aus
- **API:** Settings um neue Felder erweitern; optional `/api/wifi` oder ähnlich für Status (STA verbunden, AP an/aus)
- **Web-UI:** Neue WLAN-Sektion mit Eingabefeldern (HeimNetz-SSID, HeimNetz-Passwort, AP-SSID, AP-Passwort, AP Auto-Off in Min), Speichern-Button; Status-Anzeige (STA verbunden?, AP aktiv?, IP-Adressen)

**Architektur-Anpassung:** DPVControl macht WiFi-Setup aktuell in `webserverTask`. Für WIFI_AP_STA und handleWifiLifetime in loop() empfohlen: WiFi-Setup in `setup()` vor `setupWebserver()` verschieben (analog HeatControl). Task übernimmt nur server.begin() und Request-Loop.

**Risiko: 5/10** – Mittelhoch. WiFi-Verhalten ändert sich; Captive Portal und DNS müssen weiterhin korrekt funktionieren. Gründlich testen.

---

## 10. Auto Update – Risiko 8/10 → [#89](https://github.com/BubTec/DPVControl/issues/89)

**HeatControl:**

- AsyncWebServer mit multipart-Upload-Callback
- `/update` GET: HTML-Formular
- `/update` POST (multipart): Chunkweiser Upload, `Update.begin()`, `Update.write()`, `Update.end()`
- Web-UI: GitHub-Release-Check, Download firmware.bin, POST an `/update`

**DPVControl:**

- Synchroner WebServer; kein nativer multipart-Upload-Handler
- Kein OTA-Endpoint

**Entscheidung:** OTA auf dem bestehenden sync WebServer (Option B). Kein Wechsel zu AsyncWebServer – der aktuelle WebServer funktioniert zuverlässig. Multipart-Parsing per `client.read()` in Chunks, direkt an `Update.write()`.

**Übernahme:**

- `/update` GET: Einfache HTML-Seite mit File-Input (analog HeatControl)
- `/update` POST: Multipart-Parsing im sync WebServer, `Update`-API nutzen
- **Web-UI:** Buttons „Update prüfen“, „Auto-Update“, „Update-Seite öffnen“; Update-Banner bei neuer Version (analog HeatControl)
- **Firmware-URL:** GitHub-Release `BubTec/DPVControl` (analog HeatControl mit BubTec/HeatControl)

**Risiko: 8/10** – Hoch. OTA-Fehler können Brick verursachen. Mindestgröße prüfen, nur .bin akzeptieren, Tests mit Mock.

---

## Zusammenfassung: Risiko-Matrix (sortiert gering → hoch)

| # | Feature | Issue | Risiko | Kurzbeschreibung |
| --- | --- | ----- | --- | --- |
| 1 | Verzögerter Neustart | #81 | 1 | scheduleRestart(delayMs) |
| 2 | Cache-Control-Header | #82 | 1 | Konsistente No-Cache-Header |
| 3 | Serial Log | #83 | 2 | Rolling-Buffer + /api/logs |
| 4 | Dynamisches Log-Level | #84 | 2 | Error/Info/Debug umschaltbar |
| 5 | Erweiterte Captive-URLs  | #85 | 2 | gen_204, fwlink, etc. |
| 6 | Serial-Log-Panel (UI) | #86 | 2 | Log-Anzeige in Web-UI |
| 7 | Client-Zugriffskontrolle | #87 | 3 | 403 für nicht-lokale IPs |
| 8 | i18n DE/EN | #88 | 4 | Mehrsprachige Web-UI |
| 9 | HeimNetz + Auto AP | #90 | 5 | WIFI_AP_STA, STA-Credentials, Auto-Off |
| 10  | Auto Update | #89 | 8 | OTA multipart, Brick-Risiko |

---

## Empfohlene Reihenfolge (nach Risiko)

**Phase 1 – Risiko 1–2 (Features 1–6):**

1. Verzögerter Neustart (#81)
2. Cache-Control-Header (#82)
3. Serial Log (#83)
4. Dynamisches Log-Level (#84)
5. Erweiterte Captive-URLs (#85)
6. Serial-Log-Panel in Web-UI (#86)

**Phase 2 – Risiko 3–5 (Features 7–9):**

7. Client-Zugriffskontrolle (#87)
8. i18n DE/EN (#88) – optional, Aufwand relativ hoch
9. HeimNetz + Auto AP (#90)

**Phase 3 – Risiko 8 (Feature 10):**

10. Auto Update (#89) – zuletzt, gründlich testen

---

## Feature-Abhängigkeiten

| Feature | Issue | Abhängigkeiten | Hinweis |
| --- | ----- | --- | --- |
| 1. Verzögerter Neustart | #81 | keine | |
| 2. Cache-Control-Header | #82 | keine | |
| 3. Serial Log | #83 | keine | Backend-Basis für Feature 6 |
| 4. Dynamisches Log-Level | #84 | keine | Kann mit Feature 6 kombiniert werden |
| 5. Erweiterte Captive-URLs  | #85 | keine | |
| 6. Serial-Log-Panel | #86 | **#83** (Serial Log) | Braucht `/api/logs` Endpoint |
| 7. Client-Zugriffskontrolle | #87 | keine | |
| 8. i18n DE/EN | #88 | keine | |
| 9. HeimNetz + Auto AP | #90 | keine | Benötigt eigene WLAN-Sektion in Settings |
| 10. Auto Update | #89 | keine | |

**Reihenfolge bei Abhängigkeiten:** #86 erst nach #83 implementieren.

---

## Tiefenanalyse: Risiken, Abhängigkeiten und Konfliktstellen

### 1. Threading und Concurrency (Core 0 vs. Core 1)

| Komponente | Core | Aufrufer von log() |
| --- | ---- | --- |
| main loop() | 1 | buttonLoop, motorLoop, checkForLeak, logVehicleState, etc. |
| webserverTask | 0 | handleClient → alle API-Handler |
| vescTask | 0 | VESC-Kommunikation, battery updates |
| datalogger task | 0 | datalogLoop |

**Kritisch – Serial Log (#83):** `log()` wird von **beiden Cores** aufgerufen. Der Rolling-Buffer (`serialLogBuffer`) wird damit **concurrent** beschrieben. Ohne Synchronisation: Datenraces, korrupter Buffer.

**Lösung:** Mutex (xSemaphoreCreateMutex) um `appendLineToRollingBuffer()`; alternativ portMUX für kurze kritische Sektion.

**Kritisch – scheduleRestart (#81):** `restartScheduled` und `restartAtMs` werden vom Webserver (Core 0) gesetzt, von `loop()` (Core 1) gelesen. **Lösung:** `volatile` oder atomare Zugriffe.

### 2. WiFi-Architektur: DPVControl vs. HeatControl

| Aspekt | HeatControl | DPVControl |
| --- | --- | --- |
| WiFi-Setup  | In `setup()` vor setupWebServer | **In webserverTask** (nach Task-Start) |
| Reihenfolge | setup() → WiFi → setupWebServer | setup() → setupWebserver() → Task startet → WiFi in Task |

**Problem bei #90 (HeimNetz + Auto AP):** In DPVControl macht `webserverTask` den kompletten WiFi-Setup. Für WIFI_AP_STA brauchen wir:

- `WiFi.onEvent()` für staConnected
- `handleWifiLifetime()` in `loop()` (Core 1) – ruft `WiFi.softAPdisconnect()` auf

**Lösung:** WiFi-Setup in `setup()` vor `setupWebserver()` verschieben; Task übernimmt nur `server.begin()` und Request-Loop.

### 3. Konflikt-Matrix

| Feature A | Feature B | Konflikt |
| --- | --- | --- |
| 3 (Serial Log) | 4 (Log-Level) | Keiner – Feature 4 steuert, was Feature 3 puffert |
| 3 (Serial Log) | 6 (Log-Panel) | Keiner – 6 nutzt 3 |
| 9 (HeimNetz) | 5 (Captive-URLs) | Wenn AP aus: Captive-Portal nicht mehr relevant (nur STA) |
| 9 (HeimNetz) | 7 (Zugriffskontrolle) | isAllowedWebClient muss STA-IP (192.168.x) erlauben – bereits in 10.x, 172.16–31.x, 192.168.x |
| 1 (scheduleRestart) | 10 (OTA) | Nach OTA: Reboot. scheduleRestart verzögert – OTA sollte eigenes Reboot nach Update.end() nutzen |

### 4. Offene Punkte (entschieden)

1. **AsyncWebServer vs. sync WebServer für OTA:** Der bestehende sync WebServer kann OTA mit manuellem Multipart-Parsing. **OTA auf dem bestehenden WebServer** (Option B). Multipart-Parsing per `client.read()` in Chunks, direkt an `Update.write()`.
2. **HeimNetz-Priorität:** Wenn STA verbunden und AP nicht manuell aktiviert → AP wird abgeschaltet. **Primär über HeimNetz erreichbar**.
3. **Firmware-URL für Auto-Update:** GitHub-Release-URL fest auf `BubTec/DPVControl`.

---

## Weitere Dokumentation

- [feature_issues_to_create.md](feature_issues_to_create.md) – Manuelle Issue-Vorlagen (falls GitHub CLI nicht verfügbar)
- [.cursor/rules](../.cursor/rules) – Projektregeln für Implementierung

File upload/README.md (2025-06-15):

# Embedded Web Files System

This directory contains web files that are automatically embedded into the ESP32 firmware during compilation.

## How it works

1. **Pre-Build Process**: Before each compilation, the `embed_webfiles.py` script automatically:
   - Scans all files in this `/upload` directory
   - Converts them to C++ header files with PROGMEM data
   - Generates a registry system for the webserver
   - Places all generated files in `src/generated/` (ignored by git)

2. **Runtime**: The webserver serves files directly from embedded memory, eliminating the need for SPIFFS/LittleFS uploads

## Benefits

✅ **No Data Loss**: Web file updates no longer overwrite persistent ESP32 data (dive logs, settings, uptime)
✅ **Automatic**: Files are embedded during every build - no manual upload required
✅ **Faster**: Files are served from program memory instead of filesystem
✅ **Reliable**: No filesystem corruption issues
✅ **Version Control**: Web files are properly tracked in git

## File Structure

Place your web files directly in this directory:
- `index.html` - Main interface
- `style.css` - Styling
- `app.js` - JavaScript functionality
- `*.html` - Additional pages (settings, info, remote)
- `*.js` - JavaScript libraries
- `*.jpg`, `*.png` - Images
- Any other web assets

## Development Workflow

### Making Changes to Web Files

1. **Edit files** in this `/upload` directory
2. **Compile** normally: `python -m platformio run -e esp32dev`
3. **Upload** firmware: `python -m platformio run -e esp32dev -t upload`

The embedding happens automatically during compilation!

### File Size Considerations

- **Total recommended size**: < 1MB for all files combined
- **Individual file limit**: ~500KB per file
- **Current total**: ~640KB (see build output for exact size)

Large files (like chart.min.js) are automatically handled efficiently.

## Generated Files

The following files are auto-generated in `src/generated/` and ignored by git:
- `embedded_*.h` - Individual file headers
- `embedded_files_registry.h` - Registry header
- `embedded_files_registry.cpp` - Registry implementation

## Legacy Compatibility

The system maintains backward compatibility:
1. **First attempt**: Serve from embedded files
2. **Fallback**: Serve from SPIFFS/LittleFS if file not found in embedded storage

This ensures existing deployments continue working while benefiting from the new system.

## Migration from /data

The old `/data` directory is kept for reference but no longer used for active development. All files have been copied to this `/upload` directory.

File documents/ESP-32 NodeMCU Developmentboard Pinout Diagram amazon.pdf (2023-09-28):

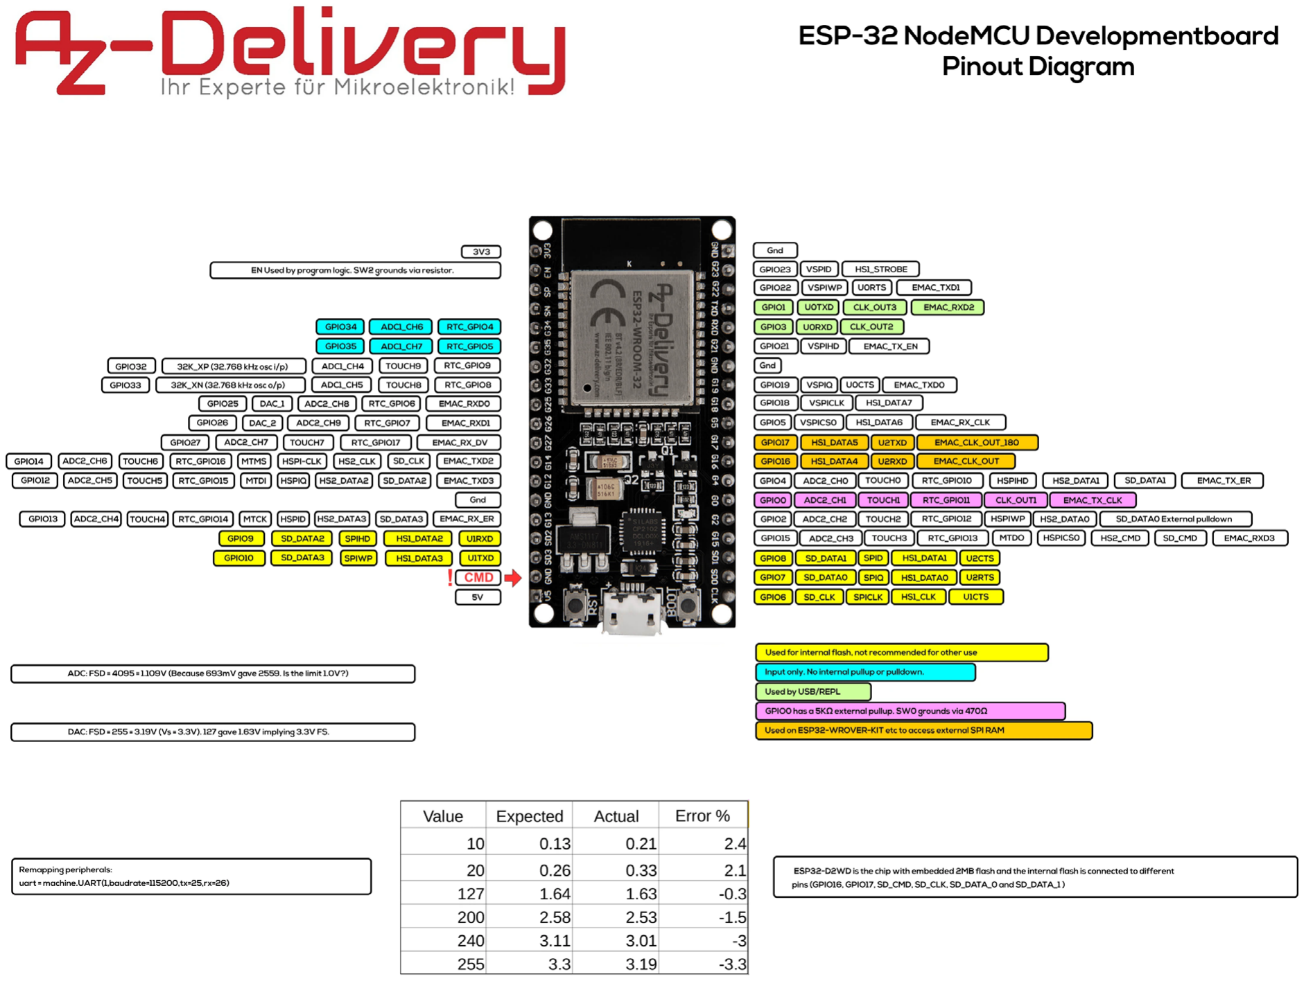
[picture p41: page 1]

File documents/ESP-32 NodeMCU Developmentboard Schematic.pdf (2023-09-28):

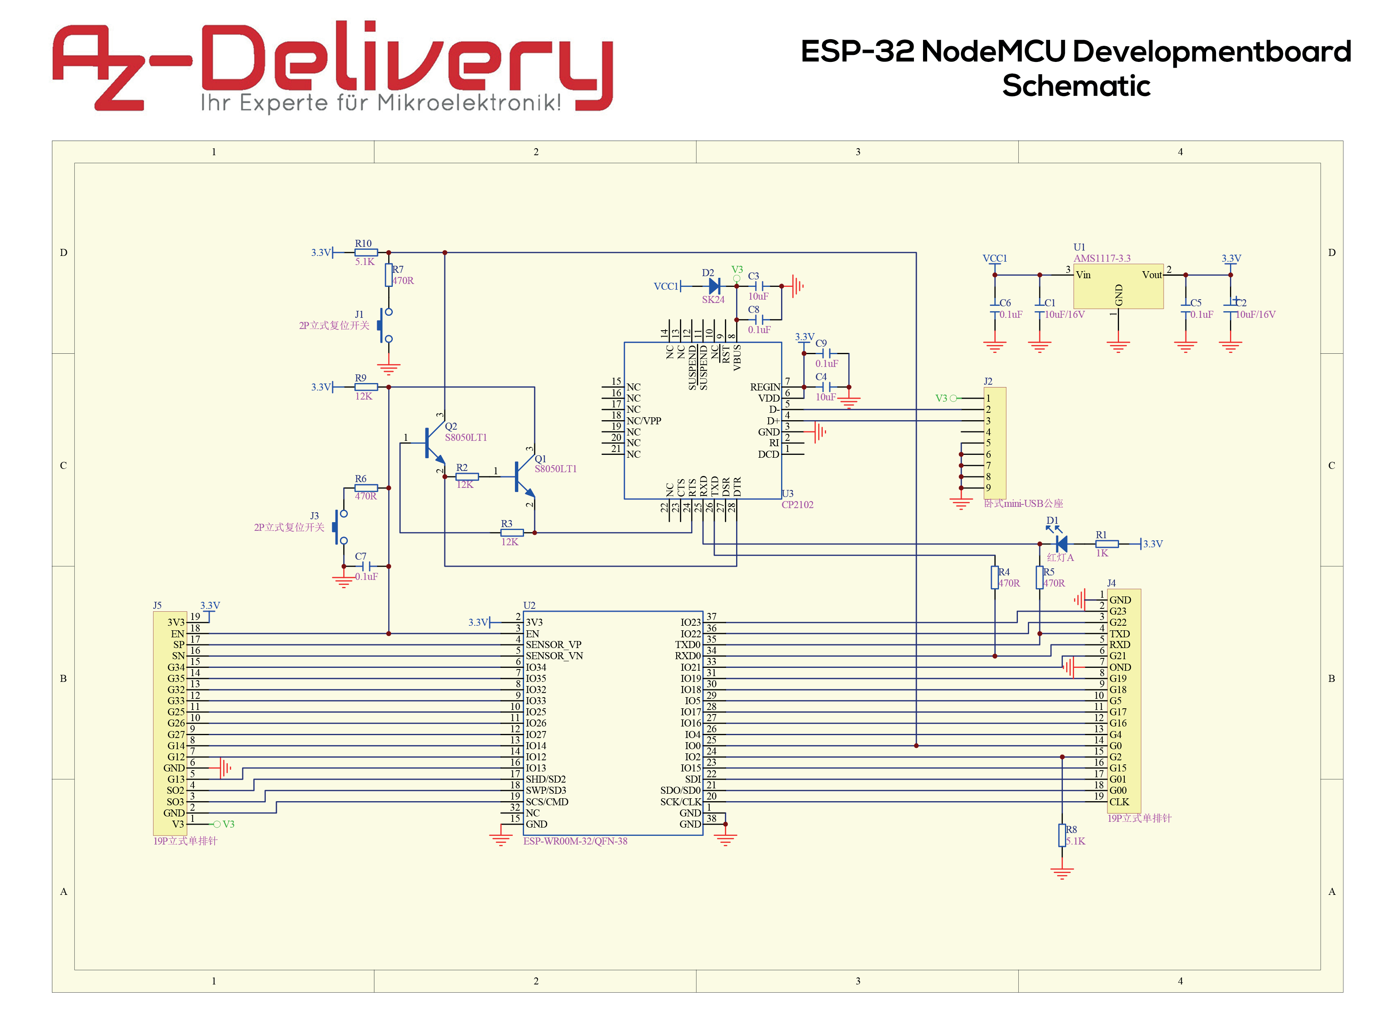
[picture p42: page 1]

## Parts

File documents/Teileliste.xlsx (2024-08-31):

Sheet: LT30-Daten
Originalteile | Gewicht (g) | Platzierung | Upgrade | Gewicht (g) | Platzierung | Gewichtsverteilung Original |  |  | Gewichtsverteilung Upgrade
Motor 3500rpm 12v 300w | 2200 | Hinten | LionAkku | 5600 | Mitte | Hinten | Mitte | Vorne | Hinten | Mitte | Vorne
Lampe | 100 | Vorne | Brusshles motor 4500rpm 48v 2000w | 4700 | Hinten | 2200 | 0 | 0 | 0 | 5600 | 0
Bleiakku 33ah 12v | 11000 | Mitte | LED | 600 | Vorne | 0 | 0 | 100 | 4700 | 0 | 0
 |  |  | Handle | 300 | Hinten | 0 | 11000 | 0 | 0 | 0 | 600
 |  |  | Elektronik | 300 | Vorne | 0 | 0 | 0 | 300 | 0 | 0
 |  |  | controller | 150 | Vorne | 0 | 0 | 0 | 0 | 0 | 300
 |  |  | Akku Schrauben | 270 | Mitte | 0 | 0 | 0 | 0 | 0 | 150
 |  |  | Akku Case | 540 | Mitte | 0 | 0 | 0 | 0 | 270 | 0
 |  |  | Notaus | 90 | Mitte | 0 | 0 | 0 | 0 | 540 | 0
 |  |  | Magnetschalter | 160 | Mitte | 0 | 0 | 0 | 0 | 90 | 0
 |  |  | Zahnkranz | 280 | Hinten | 0 | 0 | 0 | 0 | 160 | 0
 |  |  | Kabel | 300 | Mitte | 0 | 0 | 0 | 280 | 0 | 0
 |  |  | Relay | 100 | Hinten | 0 | 0 | 0 | 0 | 300 | 0
 |  |  | Sicherung | 100 | Mitte | 0 | 0 | 0 | 100 | 0 | 0
 |  |  |  |  |  | 0 | 0 | 0 | 0 | 100 | 0
Elektronik | 414 | Hinten |  |  |  | 0 | 0 | 0 | 0 | 0 | 0
Schrauben | 120 | Mitte |  |  |  | 414 | 0 | 0 | 0 | 0 | 0
Griffe | 780 | Hinten | Schrauben | 120 | Mitte | 0 | 120 | 0 | 0 | 0 | 0
Heck | 4200 | Hinten | Heck | 4200 | Hinten | 780 | 0 | 0 | 0 | 120 | 0
Tube | 4000 | Mitte | Tube | 4000 | Mitte | 4200 | 0 | 0 | 4200 | 0 | 0
Kopfteil | 1610 | Vorne | Kopfteil | 1610 | Vorne | 0 | 4000 | 0 | 0 | 4000 | 0
Summe | 24424 |  | Summe | 23420 |  | 7594 | 15120 | 100 | 9580 | 11180 | 1050
Original Gesammtgewicht | 24000
Getriebeübersetzung | 1:5 |  | Diff | 1004
Tube Umfang außen | 22,44 cm
Tube Umfang innen | 20 cm
Akkutube | 25 cm
Motorrube | 16cm
Motorabdeckung | 6 cm
Front | 13 cm
Schraubendrehzahl (ohne Last) | 700 rpm
Wellenaufname (Linksgewinde) | m6
Wellenaufteilung | 7,8 und 12mm

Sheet: Shoppinglist
Name | URL
Wellendichtring | https://www.ebay.de/itm/265634840181?chn=ps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
Kugellager | https://www.amazon.de/Edelstahl-Kugellager-12x28x8-Industriequalit%C3%A4t-S6001RS/dp/B00OV13F4C
Rillenkugellager | https://www.kugellager-express.de/rillenkugellager-6001-z-12x28x8-mm
Loctite | https://www.amazon.de/Loctite-Schraubensicherung-mittelfest-243-10/dp/B00Y8DOMCC?s=diy
Akku | https://www.amazon.de/dp/B08LVLPVJ5/?coliid=I1ZQP30XU1DG73&colid=12Y7X0Z7ZKXD1
Motor | https://www.amazon.de/dp/B0857HSF2P/?coliid=I1UJT71KYHQ7IF&colid=12Y7X0Z7ZKXD1
esc | https://de.aliexpress.com/item/1005003432486308.html?curPageLogUid=1obKiMn4yJ2h
XT90 Verbinder | https://www.amazon.de/gp/product/B07NW9RX9M/ref=ewc_pr_img_1?smid=A2JDPV3L82BNVH&psc=1
MR60 Verbinder | https://www.amazon.de/gp/product/B07ZQN1V63/ref=ewc_pr_img_2?smid=AE5BQTJHC6NVL&th=1
MosFet LED | https://www.infineon.com/cms/de/product/power/mosfet/n-channel/irfz44n/#!parametrics
LED Luminus 5000k | https://www.mouser.de/ProductDetail/Lumileds/L2C5-50701211F1900?qs=T3oQrply3y8fEmIX84JXJA%3D%3D
Rohrdichtung EPDM 210 x 3 mm | https://www.hydraulikdichtungen24.de/
Wellendichtring (10mm x 1mm)
Hochleistungsfett (Zahnkranz) | https://www.amazon.de/dp/B00295CR0U?ref_=cm_sw_r_apan_dp_03HNDJDERMAZFEYRS585

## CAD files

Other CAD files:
3D-Print/Aquazepp_Handle2 v30.f3d
3D-Print/Aquazepp_LEDDisplay v8.f3d
3D-Print/Aquazepp_Relais_Holder v5.f3d
3D-Print/Aquazepp_Röhre v90.f3d
3D-Print/Aquazepp_Schraube v5.f3d
3D-Print/Aquazepp_Zahnkranz2 v37.f3d
3D-Print/Stator v34.f3d

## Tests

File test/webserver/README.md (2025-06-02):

# Web Server Tests

This directory contains tests for the web server functionality of the DPV Control system.

## Test Structure

The tests are organized into several categories:

### Hardware Simulation
- `mock_hardware.h/cpp`: Mock implementations of hardware components
  - LED states and control
  - Motor control
  - Beeper control
  - Water sensors
  - Button states
  - LED bar (20 LEDs, split into two sections)
  - Front lamp PWM control
  - Click code functionality

### API Tests
- `test_api.cpp`: Tests for all API endpoints
  - Status endpoints
  - Data endpoints
  - Session management
  - Settings
  - Motor control
  - Lamp control
  - Beeper control
  - Version info
  - Chart data generation
  - Remote control functionality

## Test Categories

### LED Bar Tests
- Individual LED control
- Section-based control (2 sections of 10 LEDs each)
- Brightness control per section
- Pattern setting and verification
- Error cases and edge conditions

### Front Lamp PWM Tests
- PWM value setting and reading
- Duty cycle conversion
- Frequency control
- Resolution changes
- Value limits and validation

### Click Code Tests
- Basic click code functionality
- Code recording and verification
- Timeout handling
- Common click patterns
- Edge cases (very short/long clicks)
- Maximum code length

### Session Tests
- Session storage and retrieval
- CSV export functionality
- Session list management
- Data pagination
- Date range filtering

### Chart Tests
- Data format conversion
- Time range filtering
- Empty data handling
- Invalid session handling

### Remote Control Tests
- Motor control
- Lamp control
- Beeper control
- Water sensor interaction
- Button interaction
- State persistence

### Settings Tests
- Settings retrieval and update
- Settings validation
- Settings restore
- Settings persistence
- Water sensor interaction
- Button interaction

### Status Tests
- Status information retrieval
- Sensor value reporting
- System state reporting
- Water sensor states
- Button states

### Info Tests
- Version information
- Network status
- Hardware configuration
- Memory state
- Different version types

## Running Tests

To run the tests:

```bash
pio test -e native
```

## Test Coverage

The tests cover:
- All API endpoints
- Hardware interactions
- Data management
- User interface functionality
- Error handling
- Edge cases
- State management

## Adding New Tests

When adding new tests:
1. Add mock implementations in `mock_hardware.h/cpp` if needed
2. Create test cases in `test_api.cpp`
3. Follow the existing test patterns
4. Include error cases and edge conditions
5. Update this README if necessary

## Test Maintenance

- Run tests after any code changes
- Update tests when API or functionality changes
- Fix test failures before proceeding with changes
- Keep mock implementations in sync with real hardware

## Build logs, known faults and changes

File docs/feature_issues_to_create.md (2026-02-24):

# Feature Issues für HeatControl-Übernahme

Diese Datei enthält alle 10 Feature-Request-Issues zum Kopieren. Du kannst sie manuell unter https://github.com/BubTec/DPVControl/issues/new anlegen.

**Plan:** Siehe [heatcontrol_features_plan.md](heatcontrol_features_plan.md) für Kontext, Abhängigkeiten und Risikoanalyse.

**Alternative:** GitHub CLI installieren (`winget install GitHub.cli`), dann `gh auth login` und danach:
```powershell
.\.github\create_feature_issues.ps1
```

---

## Issue 1: Verzögerter Neustart

**Title:** `[FEATURE] Delayed restart (scheduleRestart) for reliable reboot response - PRIO 1`

**Labels:** enhancement

**Body:**
```
**Problem Description**
After `/api/reboot`, the ESP32 restarts immediately. The HTTP response may be cut off before the client receives it, causing the UI to show an error.

**Proposed Solution**
Delay reboot by 1–2 seconds. Set global `volatile bool restartScheduled` and `volatile unsigned long restartAtMs` in the reboot handler; check in `loop()` and call `ESP.restart()` when time has elapsed. Reference: HeatControl `scheduleRestart()`.

**Technical Requirements**
- Software: `webserver.cpp` (reboot handler), `main.cpp` (loop check)
- New globals: `restartScheduled`, `restartAtMs` (volatile)

**Acceptance Criteria**
- [ ] Reboot handler sends 200 response, sets restartScheduled, returns without immediate restart
- [ ] loop() checks flag and restarts after delay (e.g. 1200 ms)
- [ ] API spec unchanged; existing tests pass

**Implementation Notes**
- See .cursor/rules and README for project conventions.
- API spec unchanged; ensure existing /api/reboot tests still pass.
- Run `run_all_tests.ps1` before submitting.
- loop() runs on Core 1; restart check there is fine.
```

---

## Issue 2: Cache-Control-Header

**Title:** `[FEATURE] Consistent Cache-Control headers for API and HTML - PRIO 1`

**Labels:** enhancement

**Body:**
```
**Problem Description**
API and HTML responses lack consistent Cache-Control headers; browsers may cache stale data.

**Proposed Solution**
Add `Cache-Control: no-cache, no-store, must-revalidate` to all HTTP responses (API JSON, HTML, embedded files). Modify `sendHttpResponse()`, `sendEmbeddedResponse()`, and any other response paths.

**Technical Requirements**
- Software: `webserver.cpp`, `embedded_webserver.cpp`

**Acceptance Criteria**
- [ ] All API responses include Cache-Control header
- [ ] Embedded file serving includes Cache-Control header
- [ ] No functional change; only headers added

**Implementation Notes**
- See .cursor/rules and README for project conventions.
- Find all response paths: sendHttpResponse(), sendEmbeddedResponse(), and any other code that sends HTTP headers.
- No API spec or version change (headers only).
- Run `run_all_tests.ps1` before submitting.
```

---

## Issue 3: Serial Log

**Title:** `[FEATURE] Serial log buffer and /api/logs endpoint - PRIO 2`

**Labels:** enhancement

**Body:**
```
**Problem Description**
Log output is only visible via Serial; no way to view logs from the web UI. Useful for remote debugging.

**Proposed Solution**
Add rolling buffer (~12 KB), extend `log()` to append to buffer (with Mutex for multi-core safety). New endpoint `GET /api/logs` returns buffer as text/plain. Reference: HeatControl `logic_helpers::appendLineToRollingBuffer`, `serialLogBuffer`.

**Technical Requirements**
- Software: `log.cpp`, `log.h`, `webserver.cpp`
- Mutex for buffer (log() called from Core 0 and Core 1)
- api-specification.yaml: new path `/api/logs`

**Acceptance Criteria**
- [ ] All log() calls write to buffer (with mutex)
- [ ] GET /api/logs returns recent log lines as text/plain
- [ ] API spec updated; unit test for /api/logs
- [ ] No heap fragmentation; buffer fixed-size

**Implementation Notes**
- See .cursor/rules and README for project conventions.
- Use existing log() helper; extend it to append to buffer. Do NOT add new Serial.print() calls.
- Mutex required: log() is called from Core 0 and Core 1.
- API: add /api/logs to api-specification.yaml, increment API version.
- Add API test: success case (valid response) and error case (if applicable).
- Run `run_all_tests.ps1` before submitting.
```

---

## Issue 4: Dynamisches Log-Level

**Title:** `[FEATURE] Dynamic log level (Error/Info/Debug) - PRIO 2`

**Labels:** enhancement

**Body:**
```
**Problem Description**
Only boolean `debugLoggingEnabled` exists; no granular control (Error/Info/Debug).

**Proposed Solution**
Add log level (Error=0, Info=1, Debug=2). New endpoint `/api/log-level` GET/POST or extend settings. Map existing `debugLoggingEnabled`: true→Info, false→Error. Web-UI: Dropdown in Settings or Log-Panel.

**Technical Requirements**
- Software: `log.cpp`, `settings.cpp`, `webserver.cpp`, `upload/` (Web-UI)
- Settings: new field `logLevel` or replace `debugLoggingEnabled`

**Acceptance Criteria**
- [ ] Log level persistent in settings
- [ ] Only messages at or below current level are logged
- [ ] Web-UI control to change level
- [ ] Migration: existing users get Info as default

**Implementation Notes**
- See .cursor/rules and README for project conventions.
- Use existing log() helper; filter by level inside log().
- If new endpoint /api/log-level: add to api-specification.yaml, increment API version, add API tests (success + error).
- If extending settings only: update settings schema in api-spec, add tests.
- upload/ changes: run `python embed_webfiles.py`, then full PlatformIO rebuild.
- Settings migration: map debugLoggingEnabled true→Info, false→Error.
- Run `run_all_tests.ps1` before submitting.
```

---

## Issue 5: Erweiterte Captive-Portal-URLs

**Title:** `[FEATURE] Additional captive portal detection URLs - PRIO 2`

**Labels:** enhancement

**Body:**
```
**Problem Description**
Some devices (e.g. certain Android versions) use different URLs for captive portal detection. DPVControl has `/generate_204`, `/ncsi.txt`, etc., but misses `/gen_204`, `/fwlink`, and others.

**Proposed Solution**
Add redirect handlers for: `/gen_204`, `/fwlink`, `/library/test/success.html`, `/connecttest.txt.gz`, `/connecttest.txt/index.htm`, `/connecttest.txt/index.htm.gz`. Reference: HeatControl web_server.cpp lines 789–799.

**Technical Requirements**
- Software: `webserver.cpp` (path handling in handleClient)

**Acceptance Criteria**
- [ ] All listed paths redirect to portal root (4.3.2.1)
- [ ] No regression for existing captive portal behavior

**Implementation Notes**
- See .cursor/rules and README for project conventions.
- Add handlers in webserver.cpp (handleClient path handling).
- No API spec change; consider adding test for new paths and regression for existing captive portal.
- Run `run_all_tests.ps1` before submitting.
```

---

## Issue 6: Serial-Log-Panel

**Title:** `[FEATURE] Serial log panel in web UI - PRIO 2`

**Labels:** enhancement

**Body:**
```
**Problem Description**
Even with /api/logs, users need a UI to view logs. Currently no log viewer.

**Proposed Solution**
Add panel/modal with log display (pre/textarea), Log-Level dropdown, Auto-Scroll checkbox, Refresh button. Periodically fetch /api/logs. **Depends on #83** (Serial log buffer and /api/logs endpoint).

**Technical Requirements**
- Software: `upload/index.html`, `upload/app.js` (or equivalent)
- Run `embed_webfiles.py` after changes

**Acceptance Criteria**
- [ ] Log panel shows content from /api/logs
- [ ] Auto-scroll and manual refresh work
- [ ] Log-level control (or links to Issue 4)

**Implementation Notes**
- See .cursor/rules and README for project conventions.
- **Depends on #83** (Serial log buffer and /api/logs endpoint).
- upload/ changes: run `python embed_webfiles.py`, then full PlatformIO rebuild.
- Never edit src/generated/ directly.
- Run `run_all_tests.ps1` before submitting.
```

---

## Issue 7: Client-Zugriffskontrolle

**Title:** `[FEATURE] Client IP access control for write endpoints - PRIO 3`

**Labels:** enhancement

**Body:**
```
**Problem Description**
All API endpoints are accessible from any client on the AP. Write endpoints (POST) should be restricted to local networks to reduce attack surface.

**Proposed Solution**
Before processing write requests (POST/PUT), check `client.remoteIP()`. Allow: 4.3.2.x (AP subnet), 10.x, 172.16–31.x, 192.168.x. Return 403 Forbidden for others. Reference: HeatControl `isAllowedWebClient()`.

**Technical Requirements**
- Software: `webserver.cpp` (helper function, call before each write handler)

**Acceptance Criteria**
- [ ] Local clients (AP, STA) can use write endpoints
- [ ] Non-local IPs receive 403
- [ ] Read endpoints (GET) remain unrestricted (or document if restricted)

**Implementation Notes**
- See .cursor/rules and README for project conventions.
- Allow: 4.3.2.x (AP subnet), 10.x, 172.16–31.x, 192.168.x. Return 403 Forbidden for others.
- Document 403 in api-specification.yaml for affected write endpoints.
- Add API tests: local IP succeeds, non-local IP returns 403.
- Run `run_all_tests.ps1` before submitting.
```

---

## Issue 8: i18n DE/EN

**Title:** `[FEATURE] i18n: German/English language toggle - PRIO 4`

**Labels:** enhancement

**Body:**
```
**Problem Description**
Web UI is English-only (or mixed). German-speaking users would benefit from DE/EN switch.

**Proposed Solution**
Add i18n object with keys, `t(key)` function, data-i18n attributes on elements. Language toggle button. Reference: HeatControl `upload/index.html` (i18n object, langToggleBtn).

**Technical Requirements**
- Software: All files in `upload/` with user-facing text
- Run `embed_webfiles.py` after changes

**Acceptance Criteria**
- [ ] DE and EN translations for all UI strings
- [ ] Toggle persists (localStorage or similar)
- [ ] New strings use i18n; no hardcoded language-specific text

**Implementation Notes**
- See .cursor/rules and README for project conventions.
- upload/ changes: run `python embed_webfiles.py`, then full PlatformIO rebuild.
- Never edit src/generated/ directly.
- Reference: HeatControl upload/index.html (i18n object, langToggleBtn).
- Run `run_all_tests.ps1` before submitting.
```

---

## Issue 9: HeimNetz + Auto AP

**Title:** `[FEATURE] HeimNetz (STA) + Auto AP shutdown - PRIO 5`

**Labels:** enhancement

**Body:**
```
**Problem Description**
DPVControl is AP-only. Users with home WiFi want to connect via STA (HeimNetz) and optionally auto-disable AP to save power. Behavior like HeatControl.

**Proposed Solution**
Add STA (station) mode so the device can join a home network. When STA is connected, optionally disable AP to save power. When no STA for a configurable timeout, optionally disable WiFi entirely.

**Settings (new fields in settings.cpp/settings.h)**
- `staSSID` (String): Home network SSID. Empty = HeimNetz disabled, AP-only (current behavior).
- `staPassword` (String): Home network password.
- `apAutoOffMinutes` (uint16_t): Minutes without STA connection before disabling WiFi. 0 = disabled (AP stays on).
- `apManualOverride` (bool, optional): If true, keep AP on even when STA connected (e.g. for captive portal during setup).

**Boot & Connection Flow**
1. In setup(): Call initWiFi() before webserverTask starts. If staSSID non-empty: WiFi.mode(WIFI_AP_STA), start AP (existing logic), then WiFi.begin(staSSID, staPassword).
2. Register WiFi.onEvent() for ARDUINO_EVENT_WIFI_STA_CONNECTED. On connect: if !apManualOverride, schedule AP disable (e.g. set flag, disable in next loop iteration).
3. In loop(): handleWifiLifetime() – check apAutoOffMinutes timer; if STA disconnected for > apAutoOffMinutes, call WiFi.mode(WIFI_OFF) or similar.
4. webserverTask: Move AP setup into a shared initWiFi() called from setup(). webserverTask only handles HTTP, not WiFi init.

**Architecture**
- Move WiFi setup from webserverTask (line ~1906 in webserver.cpp) to setup() in main.cpp.
- New handleWifiLifetime() in main.cpp loop() – runs on Core 1 (fine for LED rule).
- WiFi.onEvent callback runs in WiFi task context; only set flags, do actual AP disable in loop() or webserverTask to avoid reentrancy.

**Web-UI (upload/)**
- New "WLAN" or "Network" section in Settings.
- Input: SSID (text), Password (password), AP auto-off (number, minutes; 0=disabled).
- Checkbox: "Keep AP on" (apManualOverride) for captive portal during first-time setup.
- Status display: "Connected to <SSID>" or "AP only", STA IP if connected, AP IP if AP active.

**Edge Cases**
- STA connect fails: Retry with backoff; show status in Web-UI. AP remains for configuration.
- User clears staSSID: On next settings save, stop STA, revert to AP-only.
- apAutoOffMinutes elapses: Disable WiFi. User must power-cycle or use physical access to re-enable (or add wake-on-WiFi if feasible).

**Reference**
- HeatControl: web_server.cpp (WiFi setup), settings for staSSID/staPassword/apAutoOffMinutes, handleWifiLifetime in loop.

**Technical Requirements**
- Software: `main.cpp`, `webserver.cpp`, `settings.cpp`, `settings.h`, `upload/`
- api-specification.yaml: extend settings schema with staSSID, staPassword, apAutoOffMinutes (and apManualOverride if added)
- Migration: empty staSSID = no HeimNetz; apAutoOffMinutes=0 = disabled

**Acceptance Criteria**
- [ ] STA connects when credentials set; AP disabled when STA connected (unless apManualOverride)
- [ ] AP auto-off after apAutoOffMinutes when no STA
- [ ] Web-UI: WLAN config (SSID, password, auto-off), status (connected/AP-only, IPs)
- [ ] Captive portal still works when AP active
- [ ] Backwards compatible: empty staSSID = current AP-only behavior

**Implementation Notes**
- See .cursor/rules and README for project conventions.
- **LED rule:** handleWifiLifetime() in loop() (Core 1) is fine. Do NOT trigger LED updates from webserverTask (Core 0).
- Settings migration: empty staSSID = no HeimNetz, apAutoOffMinutes=0 = disabled.
- Update api-specification.yaml settings schema, increment API version, add API tests for new settings.
- upload/ changes: run `python embed_webfiles.py`, then full PlatformIO rebuild.
- Run `run_all_tests.ps1` before submitting.
```

---

## Issue 10: OTA Update

**Title:** `[FEATURE] OTA firmware update via web - PRIO 8`

**Labels:** enhancement

**Body:**
```
**Problem Description**
Firmware updates require USB/serial connection. OTA allows updates via web browser.

**Proposed Solution**
Add `/update` GET (HTML form) and POST (multipart upload). Use existing sync WebServer; parse multipart manually with `client.read()` in chunks; stream to `Update.write()`. Chunk size ~4 KB. Min firmware size check (~100 KB). Only .bin accepted. Web-UI: "Update prüfen", "Auto-Update", "Update-Seite öffnen"; update banner. Firmware URL: `BubTec/DPVControl` GitHub releases.

**Technical Requirements**
- Software: `webserver.cpp`, `upload/`, `api-specification.yaml`
- Include `<Update.h>` (ESP32)
- Chunk streaming; no full firmware in RAM
- yield()/vTaskDelay(0) during upload to avoid watchdog

**Acceptance Criteria**
- [ ] GET /update serves HTML form
- [ ] POST /update accepts multipart .bin, flashes, reboots
- [ ] Invalid/small files rejected
- [ ] Web-UI: update check, auto-update from GitHub
- [ ] Unit test with mock (no real flash)
- [ ] API spec updated

**Implementation Notes**
- See .cursor/rules and README for project conventions.
- Add /update to api-specification.yaml, increment API version.
- Chunk streaming (~4 KB); no full firmware in RAM. yield()/vTaskDelay(0) during upload to avoid watchdog.
- Unit test: use mock for Update.write(); no real flash in tests.
- upload/ changes: run `python embed_webfiles.py`, then full PlatformIO rebuild.
- Run `run_all_tests.ps1` before submitting.
```

---

## Reihenfolge & Abhängigkeiten

- **Issue 6** hängt von **Issue 3** ab – zuerst Issue 3 anlegen, dann bei Issue 6 „Depends on #XX“ mit der Issue-Nummer ergänzen.
- Empfohlene Reihenfolge: 1 → 2 → 3 → 4 → 5 → 6 → 7 → 8 → 9 → 10

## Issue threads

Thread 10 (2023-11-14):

[BUG]  Branch smooth_acceleration

n3roGit, 2023-11-14:
Change SetDuty like this:

Start motor speed not 0. make it 0.2
Min speed: 0.3
max speed 1.0

happyherp, 2023-11-15:
Try version cb04071f92cc9727334097aa8c9bbf7584ddee37

The motor will now start right at 0.2 and then accelerate slowly as usual. Slowdown is unchanged.

```

14:09:21.709 -> targetMotorSpeed: 0.37
14:09:21.709 -> currentMotorSpeed: 0.20
14:09:21.740 -> currentMotorSpeed: 0.21
14:09:21.834 -> currentMotorSpeed: 0.22
14:09:21.880 -> currentMotorSpeed: 0.23
14:09:21.927 -> currentMotorSpeed: 0.24
14:09:21.974 -> currentMotorSpeed: 0.25
```

n3roGit, 2023-11-15:
I have adjusted MIN_DUTY_SOFT slightly so that it works well. But now we need a delay before the motor is started, because otherwise it wants to start directly with every click or double-click.

n3roGit, 2023-11-15:
i have just noticed something else. if i set MIN_SPEED_DUTY to 0.38, for example, which corresponds to 6000 erpm, then it starts at gear 1 (lowest level) at a value of approx. 0.44.

speed down: 1
targetMotorSpeed: 0.44
currentMotorSpeed: 0.49
currentMotorSpeed: 0.48

happyherp, 2023-11-15:
> I have adjusted MIN_DUTY_SOFT slightly so that it works well. But now we need a delay before the motor is started, because otherwise it wants to start directly with every click or double-click.

cdc9fff52e625ef821b267f744e2a8ba9262cd31 adds a delay between holding down a lever and the motor switching from off to on.

n3roGit, 2023-11-15:
> > I have adjusted MIN_DUTY_SOFT slightly so that it works well. But now we need a delay before the motor is started, because otherwise it wants to start directly with every click or double-click.
>
> [cdc9fff](https://github.com/n3roGit/DPVControl/commit/cdc9fff52e625ef821b267f744e2a8ba9262cd31) adds a delay between holding down a lever and the motor switching from off to on.

delay works great!

Closed 2023-11-16.

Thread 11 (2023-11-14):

[BUG] Hold other Lever for Stepwise Up/Down

n3roGit, 2023-11-14:
| Switch 1 | Switch 2 | Function |
|:--------:|:--------:|:--------:|
| 2 Clicks | Hold     | Stepwise slower |
| Hold     | 2 Clicks | Stepwise faster |

Please adjust the code so that one side must always be held to change the speed. currently this is not necessary to hold.

happyherp, 2023-11-15:
See 7f8cd3af7657b445089ed14b603a24b0f25b2423
With this change the speed change will only happen, if the other lever is also pressed **at the time that the other lever is released on the second click**. So you technically do not need to hold the other lever all the time, just at the very end. Implementing it in a way that the other button needs to be hold down the whole time takes more work.

n3roGit, 2023-11-15:
Perfect! Working!

n3roGit, 2023-11-15:
sorry for close

Closed 2023-11-15.

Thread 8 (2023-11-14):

[FEATURE] More Click Codes

n3roGit, 2023-11-14:
Add Click Codes for:

| Switch 1 | Switch 2 | Function |
|:--------:|:--------:|:--------:|
| 1 Click  | 1 Click  |  cruise control       |
| 2 Clicks | 2 Clicks | Boost Mode |

Cruise control hold the actual speed till you press any button.
Boost mode jump to max speed but only how long you hold the button while pressing. after one time driving in boost mode the speed goes back to old value.
maybe its easier to implement "click click hold" to enable it easier than of 3 click

n3roGit, 2023-11-17:
I've just tested cruise control. it's already working great! Please add that cruise control is also canceled if you press both buttons again. currently I have to press left or right.

happyherp, 2023-11-17:
> I've just tested cruise control. it's already working great! Please add that cruise control is also canceled if you press both buttons again. currently I have to press left or right.

I know. unfortunately that is very awkward to code. Technically, when you do anything, you leave cruise. So when you press down one lever, you already left. Then when you also click the other button at the same time, you enter cruise mode again.

happyherp, 2023-11-17:
Check a79ccb645fc679210c0aa98de0e25ad2f29ecb95 for turbo mode.
When in normal mode, do click-click-hold on both buttons at the same time. it should enter turbo mode and accelerate to 100% duty. until you let go of any of the buttons. then it returns to its normal speed.

n3roGit, 2023-11-17:
almost perfect. the only thing missing is the setBarSpeed set to maximum during turbo. then we can merge

n3roGit, 2023-11-17:
and maybe add that the boost stays on as long as you keep pressing at least one button. but that's just a nice to have.

happyherp, 2023-11-17:
Both those things should work now. Try eab7424313f01328d96973a071e42a7cf1ae587f

Closed 2023-11-17.

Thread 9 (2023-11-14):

[FEATURE] PreventOverload

n3roGit, 2023-11-14:
Finish PreventOverload function.

i need pre defined reductions for OverloadLimitMax like actual.

if motor draw more than OverloadLimit, the motor is spinning slower but if the load is lower it goes back to old value of speed.

happyherp, 2023-11-16:
What? Auf deutsch bitte.

n3roGit, 2023-11-16:
OverloadLimitMax = 40: definiert den Wert, den der Akku maximal liefern kann
OverloadLimit: Ist der Wert den der Motor benutzen kann ohne den Akku zu überlasten.

Da der VESC lediglich den Stromverbrauch des Motors messen kann und andere Verbraucher nicht einbezieht folgende Idee:

Es werden Bedingungen definiert, welche basierend auf statischen werden die maximal verfügbaren Ampere errechnen.

Bsp:
LED auf Stufe 3 verbraucht 3 A
OverloadLimit = OverloadLimitMax - LED auf Stufe 3
37                    = 40                           - 3

In diesem Beispiel darf der Motor maximal 37 Ampere aufnehmen.

Wird das Limit während des fahrens erreicht muss automatisch die Geschwindigkeit reduziert werden.

happyherp, 2023-11-19:
check 07b0548037f4985760301fb90ca0388e85310b99
I also added beeps at various points to alert the rider about what is going on.

n3roGit, 2023-11-19:
works perfectly. that i can put in production. currently there is still a merge problem

Closed 2023-11-19.

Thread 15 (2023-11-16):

[BUG] Motor acceleration - PRIO 1

n3roGit, 2023-11-16:
const double DUTY_FACTOR = 1.0;
const double MIN_SPEED_DUTY = 0.38; //Duty on lowest setting.
const double MIN_DUTY_SOFT = 0.23; //Minumum Duty we sent to the motor during soft acceleration.
const double DUTY_SOFT_SKIP = 0.15;

Please add the following here. I would like to be able to exclude a certain range in the DutyCycle, e.g. 0.15 - 0.23. Unfortunately, the engine stutters in this range. This allows me to guarantee a smooth start from 0.

In addition, the first speed level is currently not correct.
speed down: 1
corresponds to
currentMotorSpeed: 0.43 and not 0.38

happyherp, 2023-11-17:
try this: 592d2aaee92e4f046086101a1d33ef6d82efad86

n3roGit, 2023-11-17:
Hmm that still behaves totally stupid. I think we should go back to setRMP. that worked best =)

happyherp, 2023-11-21:
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

I fix this in production branch on a83f71a884d902662322ecad4a1c18942f48a526

happyherp, 2023-11-21:
See Commit 06fab3a49425af747aeffdc711c9a0dedc78a180 on the new branch. It uses RPM again.

n3roGit, 2023-11-22:
https://github.com/n3roGit/DPVControl/issues/37

n3roGit, 2023-12-30:
@happyherp  could we close this?

happyherp, 2023-12-30:
Yep. I will also delete the branch skip_duty_range where I did the changes.

Closed 2023-12-30.

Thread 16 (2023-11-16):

[FEATURE] Button Codes

n3roGit, 2023-11-16:
if (rightButton.clicks == 3) {
    toggleLED();
  }
  if (leftButton.clicks == 3) {
    flash();
  }
  if (leftButton.clicks == 4) {
    outputBatteryInfo();
  }

  I think the button function is already very good. Ideally, I would include all possible combinations that are easy to implement here, even if we are not currently using them.

I would currently remove the flash() function from the 3 click and use outputBatteryInfo() again.

n3roGit, 2023-11-17:
Low Prio

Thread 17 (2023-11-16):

[FEATURE]  battery level

n3roGit, 2023-11-16:
`void updateBatteryLevel(float voltage) {
  if (voltage >= 5 && CellsInSeries >= 2) {
    float singleCellVoltages[] = {4.18, 4.1, 3.99, 3.85, 3.77, 3.58, 3.42, 3.33, 3.21, 3.00, 2.87};
    int singleCellPercentages[] = {100, 96, 82, 68, 58, 34, 20, 14, 8, 2, 0};

    for (int i = 0; i < sizeof(singleCellVoltages) / sizeof(singleCellVoltages[0]); i++) {
      if (voltage >= singleCellVoltages[i] * CellsInSeries) {
        // Interpolation
        if (i > 0) {
          float voltageRange = singleCellVoltages[i] * CellsInSeries - singleCellVoltages[i - 1] * CellsInSeries;
          int percentageRange = singleCellPercentages[i - 1] - singleCellPercentages[i];
          float voltageDifference = singleCellVoltages[i] * CellsInSeries - voltage;
          float interpolationFactor = voltageDifference / voltageRange;
          batteryLevel = singleCellPercentages[i] + interpolationFactor * percentageRange;
        } else {
          batteryLevel = singleCellPercentages[i];
        }
        break;
      }
    }
    // Ensure that the battery level is limited to the range [0, 100]
    batteryLevel = constrain(batteryLevel, 0, 100);
  } else {
    batteryLevel = 100;
  }
  int steps = (batteryLevel + 5) / LedBar2_Num;
  steps = constrain(steps, 0, LedBar2_Num - 1);
  setBarBattery(steps);
}`

I currently see a few improvements here.

1. make singleCellVoltages and singleCellPercentages into one table.
2. always use the average of the last X values to calculate the battery level. this is necessary because the voltage can drop briefly during acceleration. this means that for a moment, for example, only 30% of the battery is displayed, although 80% is actually still available. Here I would work with a measurement over at least the last 60 seconds.

n3roGit, 2023-11-17:
the output looks correct

n3roGit, 2023-11-17:
the calculation is as follows:

    float singleCellVoltages[] = {4.18, 4.1, 3.99, 3.85, 3.77, 3.58, 3.42, 3.33, 3.21, 3.00, 2.87};
    int singleCellPercentages[] = {100, 96, 82, 68, 58, 34, 20, 14, 8, 2, 0};

   The following is calculated for a 13S battery:

   40V / 13S = 3,08 -> between 8 and 2%

happyherp, 2023-11-18:
7227eb48cd6741c98750ec1d691655b5093dafec has a refactored soc calculation, which still works the same. It also records voltage and uses the average to calculate soc.

n3roGit, 2023-11-19:
implemented

Closed 2023-11-19.

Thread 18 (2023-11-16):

[FEATURE] Write long time Data

n3roGit, 2023-11-16:
https://github.com/siara-cc/esp32_arduino_sqlite3_lib
https://medium.com/@ladolcefarniente/save-data-input-to-spiffs-with-esp32-and-arduino-ide-9e37011d7a91

Ideally, we can store a lot of data during operation on the 4MB memory of the ESP in order to analyze it after use. a possible variant could be to use the library linked above.

Spontaneously I can think of the following data for the database:
- Total operating time
- Motor Temp
- VESC Temp
- DHT22 Temp/Humidity
- UART.data.inpVoltage
- UART.data.avgInputCurrent
- UART.data.rpm
- Batterylevel

I

happyherp, 2023-11-19:
version on the branch starts a csv-file on startup.
Every second we record time and temperature and write to it.
Every startup uses a new file.
As far as I can tell there is no easy way to access the file system.

n3roGit, 2023-11-19:
`beepSequence:1
 still in standby: 1
Connected to VESC.
E (1027) SPIFFS: mount failed, -10025
writing to /datalog/data_0.csv
Listing directory: /datalog
  FILE: data_0.csv	SIZE: 0
Booting finished!
beepSequence:1
currentMotorSpeed: 0.00
Creating datapoint
Creating datapoint
Creating datapoint
Creating datapoint
Creating datapoint
Creating datapoint`

i got this after flashing

happyherp, 2023-11-19:
yep. that means its writing to a file. Now how do we read it? I would do it via wifi.

n3roGit, 2023-11-19:
Yes with wifi

happyherp, 2023-11-22:
I'll start the wifi implementation in this issue then.

I like the [AdvancedWebsocket ](https://github.com/espressif/arduino-esp32/blob/master/libraries/WebServer/examples/AdvancedWebServer/AdvancedWebServer.ino) better than working directly with the http-stream and having to write and parse http-headers myself like they do here: https://randomnerdtutorials.com/esp32-web-server-arduino-ide/

happyherp, 2023-11-22:
Having some trouble here .Stuck in this loop

```
  while (WiFi.status() != WL_CONNECTED) {
    delay(500);
    Serial.print(".");
    Serial.print(WiFi.status());
  }

```
Output is status:1([WL_NO_SSID_AVAIL](https://www.arduino.cc/reference/en/libraries/wifi/wifi.status/)) and stays there.

This guys seems to have a similiar problem: https://forum.arduino.cc/t/wifi-stopped-connecting-esp8266/593080/3
and fixed it by using another board firmware, I think.

54758fa9469cf5dd64692999ea0452106abe8c1a this is the code i tried. @n3roGit can you check it out?

n3roGit, 2023-11-22:
This is because in this configuration the esp tries to dial into your wifi. However, we want to use the AP mode.

Have a look here:
https://github.com/n3roGit/DPVControl/issues/20

That's what I was referring to =)

happyherp, 2024-01-12:
We will need some kind of templating library to insert things into the html. There is the standard https://github.com/plapointe6/EspHtmlTemplateProcessor . But I don't think it will be enough.

I would like to try https://github.com/me-no-dev/ESPAsyncWebServer . But that requires plattformIO, which is another vsCode plugin. So i will try that.

n3roGit, 2024-01-15:
I can try to do that. Can't we use the web server that is currently working?

happyherp, 2024-03-10:
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

I added the missing fields to the csv file. Motor values are all dummy, as I don't have one on my board. You should run it with the real thing, so we can adjust the formatting.  @n3roGit

n3roGit, 2024-03-10:
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
[logs (4).csv](https://github.com/n3roGit/DPVControl/files/14549693/logs.4.csv)

Looks great. i have niticed that i have two 0 csv files after delete. and i have attached the new generated log =)

happyherp, 2024-03-10:
the log looks ok, i would say. maybe we could display motor rpm without decimal places...

happyherp, 2024-03-10:
also added: display of file size in list; logging of led lamp state.

happyherp, 2024-03-10:
also logging: motorstate, speedsetting.

n3roGit, 2024-03-10:
Really Great!

Please add:

Battery Percentage
motorState
OverAllRuntime
WaterSensor State (Front and Back)

n3roGit, 2024-03-10:
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

Looks Nice. Why i have two files frome time to time?

happyherp, 2024-03-10:
> Looks Nice. Why i have two files frome time to time?

Not sure. But it is the file we are currently writing to. Can you live with that?

n3roGit, 2024-03-10:
> > Looks Nice. Why i have two files frome time to time?
>
> Not sure. But it is the file we are currently writing to. Can you live with that?

Yes its OK

n3roGit, 2024-03-10:
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

Only this would be usefull

happyherp, 2024-03-10:
> OverAllRuntime

That one is a bit more work. The timer resets with the machine. I would need to create a file to get the value from the last run. And regularly overwrite it to have the value for the next time, because we could be turned off at any moment. Please make a separate ticket for that one.

> Battery Percentage
> WaterSensor State (Front and Back)

Those are easy.. will add.

n3roGit, 2024-03-10:
After the last update, the water sensor goes to 1 at the front and rear after starting.

n3roGit, 2024-03-10:
I have a simple solution to create graphs from the CSV:

https://webutility.io/csv-to-chart-online

Simply upload the file there as it is.

n3roGit, 2024-03-10:
@happyherp I have found another critical error in the current firmware. For some reason, both water sensors go TRUE. Even a restart does not fix this.

happyherp, 2024-03-10:
> I have found another critical error in the current firmware. For some reason, both water sensors go TRUE. Even a restart does not fix this.

Weird. I am pretty sure, that I did not change the code. But it looked weird to me as well, because it had SENSOR == LOW.

I negated the sensors. Try again?

n3roGit, 2024-03-10:
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

No this isnt the solution. after the following commit its broken:

https://github.com/n3roGit/DPVControl/commit/0706cedec54c6233f299dc0e2ed16455dcd82113

n3roGit, 2024-03-10:
I suspect that it only occurs when the VESC is connected. It also looks like this in the log.

If I leave the VESC connected while the ESP is already receiving power via USB, I can reproduce the error.

` Failed to get VESC data!: 0
 Loop took: 101
 Failed to get VESC data!: 0
 Loop took: 101
 Failed to get VESC data!: 0
 Loop took: 101
 Failed to get VESC data!: 0
 Loop took: 101
 Failed to get VESC data!: 0
 Loop took: 101
 Failed to get VESC data!: 0
 Loop took: 101
 Failed to get VESC data!: 0
 Loop took: 101
 Failed to get VESC data!: 0
 Loop took: 101
 Failed to get VESC data!: 0
 Loop took: 101
 Loop took: 116
beepSequence:12121212
 WARNING LEAK: 12121212
beepSequence:12121212
 WARNING LEAK: 12121212
beepSequence:12121212
 WARNING LEAK: 12121212
beepSequence:12121212
 WARNING LEAK: 12121212
beepSequence:12121212
 WARNING LEAK: 12121212
beepSequence:12121212
 WARNING LEAK: 12121212
beepSequence:12121212
 WARNING LEAK: 12121212
beepSequence:12121212
 WARNING LEAK: 12121212
beepSequence:12121212
 WARNING LEAK: 12121212
beepSequence:12121212
 WARNING LEAK: 12121212
beepSequence:12121212
`

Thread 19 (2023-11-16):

[FEATURE] Emergency stop - PRIO 2

n3roGit, 2023-11-16:
We need to monitor the value for getVescUart().data.rpm while the motor is running. If it is not approaching the desired speed as expected or if it suddenly stops, we assume that something has jammed. the motor must then be stopped immediately.

You could also use getVescUart().data.avgInputCurrent, as a strong fluctuation in the current consumption could also be an indication.

happyherp, 2023-11-21:
I put this in the motor_by_rpm branch.
36f21eea86435f680d1b420bdd84f893a5a3935c

n3roGit, 2023-11-22:
https://github.com/n3roGit/DPVControl/issues/37

n3roGit, 2023-11-23:
> I put this in the motor_by_rpm branch.
> 36f21eea86435f680d1b420bdd84f893a5a3935c
>

Whats happening when motor is jammed on startup? In this case ampere rises and we have no RPM

n3roGit, 2024-01-06:
.

Closed 2024-01-06.

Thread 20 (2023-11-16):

[FEATURE] Webgui - PRIO 3

n3roGit, 2023-11-16:
Once the basic functionality has been achieved, a webgui is required for the device.
How it could look is already described here. This template should only be seen as a suggestion. If it makes sense to design a significantly simplified website, I prefer this.

https://github.com/n3roGit/DPVControl/blob/production/DPVController/status.html
https://github.com/n3roGit/DPVControl/blob/production/GUI.png

Here is a link on how to use a web server on the ESP.
https://randomnerdtutorials.com/esp32-web-server-arduino-ide/
https://github.com/espressif/arduino-esp32/blob/master/libraries/WebServer/examples/AdvancedWebServer/AdvancedWebServer.ino

I would want to use the ESP in AP mode, where it sets up its own network that you can connect to.

n3roGit, 2024-11-11:
https://github.com/n3roGit/HeatControl

We can take a look at the web server and configuration in the project mentioned.

n3roGit, 2025-05-25:
Implemented in https://github.com/BubTec/DPVControl/tree/18-feature-write-long-time-data---prio-3-try_v2

Closed 2025-05-28.

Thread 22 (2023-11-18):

[BUG] Battery Level not calculated without USB Serial  - PRIO 2

n3roGit, 2023-11-18:
I have noticed that the LED indicator is not activated if I do not have a USB cable connected.

I have now narrowed it down to the fact that the updateBatteryLevel function is only executed when I have USB connected.

I found this out by beeping when the function is executed.

`void updateBatteryLevel(float voltage) {
  if (voltage >= 5 && CellsInSeries >= 2) {
    float singleCellVoltages[] = {4.18, 4.1, 3.99, 3.85, 3.77, 3.58, 3.42, 3.33, 3.21, 3.00, 2.87};
    int singleCellPercentages[] = {100, 96, 82, 68, 58, 34, 20, 14, 8, 2, 0};

    for (int i = 0; i < sizeof(singleCellVoltages) / sizeof(singleCellVoltages[0]); i++) {
      if (voltage >= singleCellVoltages[i] * CellsInSeries) {
        // Interpolation
        if (i > 0) {
          float voltageRange = singleCellVoltages[i] * CellsInSeries - singleCellVoltages[i - 1] * CellsInSeries;
          int percentageRange = singleCellPercentages[i - 1] - singleCellPercentages[i];
          float voltageDifference = singleCellVoltages[i] * CellsInSeries - voltage;
          float interpolationFactor = voltageDifference / voltageRange;
          batteryLevel = singleCellPercentages[i] + interpolationFactor * percentageRange;
        } else {
          batteryLevel = singleCellPercentages[i];
        }
        break;
      }
    }
    // Ensure that the battery level is limited to the range [0, 100]
    batteryLevel = constrain(batteryLevel, 0, 100);
  } else {
    batteryLevel = 100;
  }
  int steps = (batteryLevel + 5) / LedBar2_Num;
  steps = constrain(steps, 0, LedBar2_Num - 1);
  setBarBattery(steps);
  beep("1111111111");  <------ HERE ----
}`

n3roGit, 2023-11-18:
if (UART.getVescValues()) {
    Serial.println("Connected to VESC.");
  } else {
    Serial.println("Failed to connect to VESC.");
    //hasMotor = false;
  }

  I was able to "solve" it. Apparently hasMotor is set to false at startup. Maybe we need to make a second function that also sets it back to true when connected.

happyherp, 2023-11-18:
That was something i build in to be able to work with my local setup without a motor. I don't quite understand, why it also is triggered if there is no usb.

happyherp, 2023-11-21:
I am not sure how to continue here.

n3roGit, 2023-11-22:
yes, that's strange. maybe we do that via a control file that is included in the gitignore. if "noMotor" file exists, then ignore it. This would also prevent the device from setting its dinest during operation in the event of communication problems at startup.

Or something with #ifdefine

n3roGit, 2023-11-23:
Or me make it in the gui to enable and disable it

n3roGit, 2023-12-30:
@happyherp Today I had something similar with motor jammed. The engine runs without the serial. Not with serial on.

happyherp, 2023-12-30:
I assume this is the same problem caused by getVescUart() returning a copy instead of a reference. I fixed that. Can you try it out?

3f0ad9f5f18cc0bd1925bff598ee3d7151f1cb4b

n3roGit, 2023-12-30:
bat lvl: 0
up 0 days, 0 hours, 1 minutes, 12 seconds
RPM: 0.00
inpVoltage: 0.00
ampHours: 0.00
tempMosfet: 0.00
tempMotor: 0.00
wattHours: 0.00
avgInputCurrent: 0.00
avgMotorCurrent: 0.00
dutyCycleNow: 0.00
Temp: 22.40°C
Humidity: 57.3%

Testen branch 22 but no differents

happyherp, 2024-01-02:
Is it still the same problem? Because I don't understand how you got a log-output without serial on.
That is something we should fix anyways. Additionally to writing to serial, i should also be logging to the microcontrollers filesystem. Like we do in https://github.com/n3roGit/DPVControl/issues/18

Closed 2024-01-06.

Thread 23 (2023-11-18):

[FEATURE]  Powerbank

n3roGit, 2023-11-18:
| Switch 1 | Switch 2 | Function |
|:--------:|:--------:|:--------:|
| 3 Clicks | 3 Clicks |      PowerBank ON/OFF     |

I would also like to have an external power supply via the device's battery. This power bank function must be switchable on and off.

The function for the display is already implemented:

setBarPowerBank();

For this, PIN_POWERBANK is set to either HIGH or LOW.

Here it is crucial that PowerBank is ALWAYS off initially. In addition, we need to add PreventOverload to reduce the maximum available power of 10A when the powerbank is active.

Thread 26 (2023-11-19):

Move away from arduino IDE - PRIO ?

happyherp, 2023-11-19:
I dont like the IDE of Arduino that much. It was nice to get started, but i think there are better tools out there.

I don't like the .ino files. It makes me create to many global variables.
Also sometimes the arduino compiler seems to move declarations around that cause strange bugs.

happyherp, 2023-11-19:
I see there already is a branch https://github.com/n3roGit/DPVControl/tree/test-visual-studio-code

i am looking at this tutorial...
https://colddsam.medium.com/exploring-the-world-of-arduino-programming-in-visual-studio-code-bbcb4af982e7

happyherp, 2023-11-19:
What seems to work ok-ish.
VSCode with Arduido plugin from microsoft.
then install gcc compiler. https://nuwen.net/mingw.html
select the compiler in vscode.
then install the libraries that we use from inside vscode using the arduino library manager. If some are missing they need to be put in C:\Users\<user>\Documents\Arduino\libraries so that they can be found there.

with that I can currently run verify and also upload to the board.
But there are MANY compilation errors. Most probably because of the .ino files. To fix this we would need to make them all .h/.cpp

happyherp, 2023-11-20:
i converted almost all code to cpp.

Still my configuration shows wrong errors:
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

n3roGit, 2023-11-21:
I think he is missing some default librarys. I search for this problem

n3roGit, 2023-11-21:
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

i got only this message with vscode branch

n3roGit, 2023-11-21:
check this https://github.com/n3roGit/DPVControl/commit/f5c7687e6f8adc7d1396db4811dcc097611e2076
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

with this its building bot not 100%
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

ö

n3roGit, 2023-11-21:
HA, Now its working!!!!!!!!

I can flash!

n3roGit, 2023-11-21:
Ah you need one thing:
https://downloads.arduino.cc/arduino-cli/arduino-cli_latest_Windows_64bit.msi
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
And set the CLI as compiler
C:\Program Files\Arduino CLI\

n3roGit, 2023-11-21:
After the changeover, communication with the vesc no longer works. we should take another look at this.

n3roGit, 2023-11-21:
tried:
`  if (getVescUart().getVescValues()) {
    Serial.println("Connected to VESC.");
  } else {
    Serial.println("Failed to connect to VESC.");
    hasMotor = true;
  }`

  and got this;

  ` Failed to get VESC data!: 0
 Failed to get VESC data!: 0`

n3roGit, 2023-11-21:
https://github.com/microsoft/vscode-arduino

i try it like this. working on it

n3roGit, 2023-11-21:
https://github.com/microsoft/vscode-arduino/blob/374c78f8ed06c1e88df480b687c24c06b728e13b/README.md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

`- The supported legacy Arduino IDE versions are `1.6.x` and up to, but not including, `2.0.0`.
- The Windows Store's version of the Arduino IDE is not supported because of the sandbox environment that the application runs in.
- *Note:* Arduino IDE `1.8.7` had some breaking changes, causing board package and library installation failures.  These failures were corrected in `1.8.8` and later.
- *Note:* Arduino IDE `2.X.Y` is not supported and there are no plans for support in the future ([issue 1477](https://github.com/microsoft/vscode-arduino/issues/1477)).
`

happyherp, 2023-11-21:
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
That sums up the situation. Files are there, and vscode seems to know where. But CodeAnalysis does not find them.

happyherp, 2023-11-21:
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

That is coming from somewhere else.
See the other.cpp

```
void GetVESCValues() {

  if (!hasMotor) return;

  if (getVescUart().getVescValues()) {
    /*
    Serial.print("RPM: ");
    Serial.println(UART.data.rpm);
    Serial.print("inpVoltage: ");
    Serial.println(UART.data.inpVoltage);
    Serial.print("ampHours: ");
    Serial.println(UART.data.ampHours);
    Serial.print("tachometerAbs: ");
    Serial.println(UART.data.tachometerAbs);
    */

    updateBatteryLevel(getVescUart().data.inpVoltage);
  } else {
    log("Failed to get VESC data!", 00000);
  }
}
```

n3roGit, 2023-11-21:
> 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
> That sums up the situation. Files are there, and vscode seems to know where. But CodeAnalysis does not find them.

Maybe need to disable this feature?

happyherp, 2023-11-21:
I will disable it. I wanted to have the static c++ code analysis. But it is still better than Arduino IDE. I will merge what we have to prod and move on.

Closed 2023-11-21.

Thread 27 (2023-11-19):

[BUG] Cruise Control - PRIO 1

n3roGit, 2023-11-19:
I have just noticed the following.
When I activate CruiseControl and let the engine run, it goes into standby after 60 seconds and stops the engine.

`currentMotorSpeed: 0.90
currentMotorSpeed: 0.91
currentMotorSpeed: 0.92
currentMotorSpeed: 0.94
currentMotorSpeed: 0.95
currentMotorSpeed: 0.96
currentMotorSpeed: 0.97
currentMotorSpeed: 0.98
currentMotorSpeed: 1.00
 going to standby: 100430010
beepSequence:2
targetMotorSpeed: 0.00
currentMotorSpeed: 0.97
`

happyherp, 2023-11-21:
try 3f463a4c3c4d469624d3ed844a42e7e67d535e06

Closed 2023-12-30.

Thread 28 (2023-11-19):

[BUG] StandbyBlinkDuration - PRIO 3

n3roGit, 2023-11-19:
I have noticed that StandbyBlinkStart works correctly. However, the pattern is not repeated every 10 seconds as currently described in StandbyBlinkDuration.

const int StandbyBlinkStart = 15;         // Minutes for blink start
const int StandbyBlinkDuration = 10;      // Seconds between blink

Closed 2024-01-06.

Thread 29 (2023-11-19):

[BUG] double beep when going to standby - PRIO 3

n3roGit, 2023-11-19:
i have noticed that i get two beeps when the device goes into standby.

Beep for going to standby and for still on standby = 21

```
 going to standby: 203259027
beepSequence:2
beepSequence:1
 still in standby: 1
```

happyherp, 2023-11-21:
try this d942c9b6cf0ce58863c2b21d5877d8881adbc3fd

Closed 2023-11-22.

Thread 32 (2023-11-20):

[FEATURE] display uptime and overall runtime in gui - PRIO 6

n3roGit, 2023-11-20:
It would be nice to see the current runtime and the total runtime of the device on the Webgui. This information must be stored on the flash of the ESP.

n3roGit, 2025-05-25:
Fixed in https://github.com/BubTec/DPVControl/tree/18-feature-write-long-time-data---prio-3-try_v2

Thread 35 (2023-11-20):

[FEATURE] setBarFlasher - PRIO 10

n3roGit, 2023-11-20:
I have added `setBarFlasher`. It would be great if `setBarFlasher` was triggered when `flash()` was executed. Of course, `setBarFlasher` should only be displayed while `flash()` is active. Afterwards, the previous display must be restored. The restoration of the previous display should also be implemented in a few additional places, since it can currently happen that no LEDs remain lit at all. Ideally, if a different indicator has been shown, the current gear level should automatically be re-displayed after 30 seconds.

Closed 2025-05-23.

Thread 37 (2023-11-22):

[BUG]  VESC Communication - PRIO 1

n3roGit, 2023-11-22:
After we have made the division into different h files, the communication to the vesc somehow no longer works. Unfortunately, this means I can't test the current adjustments to rpm. do you want to have a look together tomorrow?

n3roGit, 2023-11-22:
The error is between the commit
https://github.com/n3roGit/DPVControl/commit/3b656e03349a84c7121f943b9b893088a5881856
and
https://github.com/n3roGit/DPVControl/commit/d3b80c0e3ce4261f12973a5b46ac25908da5e564

The upper one works

Closed 2023-12-30.

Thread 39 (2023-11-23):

[FEATURE] enable/disable function over gui - PRIO 10

n3roGit, 2023-11-23:
It wold be nice to enable and disable the following functions over gui.

Emergency stop
Beeper
Led bar
Front led
Leak sensor
Dht

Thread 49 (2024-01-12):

[FEATURE] Remote Control over gui - PRIO 8

n3roGit, 2024-01-12:
It would be quite nice if you could also trigger actions via the GUI. that would be great for testing. maybe you could also clamp the device in front of a boot and then control it with your cell phone :D

`<!DOCTYPE html>
<html lang="en">
<head>
    <meta charset="UTF-8">
    <meta name="viewport" content="width=device-width, initial-scale=1.0">
    <title>Device Remote control</title>
    <style>
        /* Hier fügen wir den bereits vorhandenen Stil aus deiner Vorlage ein */
        /* ... Dein vorheriger Stil ... */

        /* Zusätzlicher Stil für die neuen Schaltflächen */
        .control-button {
            background-color: #3498db;
            border: none;
            color: white;
            padding: 10px 20px;
            text-align: center;
            text-decoration: none;
            display: inline-block;
            font-size: 16px;
            margin: 4px 2px;
            cursor: pointer;
            border-radius: 4px;
            transition: background-color 0.3s;
        }

        .control-button:hover {
            background-color: #2c3e50;
        }
    </style>
</head>
<body>
    <div class="container">
        <h2>Gerätesteuerung</h2>
        <div class="section">
            <!-- Steuerungsschaltflächen -->
            <button class="control-button">Start</button>
            <button class="control-button">Stop</button>
            <button class="control-button">Lampe An/Aus</button>

            <h3>Lampenstufen</h3>
            <button class="control-button">Lampenstufe 0</button>
            <button class="control-button">Lampenstufe 1</button>
            <button class="control-button">Lampenstufe 2</button>
            <button class="control-button">Lampenstufe 3</button>
            <button class="control-button">Lampenstufe 4</button>
        </div>
    </div>

    <!-- Hier fügen wir dein vorhandenes JavaScript und andere Elemente ein -->
    <!-- ... Dein vorheriges JavaScript und andere Elemente ... -->
</body>
</html>
`

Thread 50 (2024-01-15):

[FEATURE] CaptivePortal for web GUI - PRIO 8

n3roGit, 2024-01-15:
https://github.com/espressif/arduino-esp32/blob/master/libraries/DNSServer/examples/CaptivePortal/CaptivePortal.ino

Ideally, the controller's website is automatically displayed on the end device after connecting to the ESP. This is possible with CaptivePortal.

As with the Hotel Wifi, a popup is then displayed which refers to the GUI.

n3roGit, 2024-11-11:
https://github.com/n3roGit/HeatControl

We can take a look at the web server and configuration in the project mentioned.

Closed 2025-05-28.

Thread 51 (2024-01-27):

[BUG] when using full speed mode for long time the vehicle goes into standby.

happyherp, 2024-01-27:
**Describe the bug**

If you use the click-and-hold on both levers to enter full speed mode and stay there for a long time, the system will eventually go into standby. This should not happen.

**Expected behavior**
While in full-speed mode it should not enter standby. Leaving full-speed mode should count as an action and reset the stand-by timer.

Closed 2024-01-27.

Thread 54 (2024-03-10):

[FEATURE] compress CSV after write - PRIO 4

n3roGit, 2024-03-10:
I think we could save disk space if the CSV files are always compressed when a new file is started.

Maybe that works with:
https://github.com/warmcat/lws-esp32-factory/blob/master/components/zlib/zlib.h

n3roGit, 2025-05-25:
Fixed in https://github.com/BubTec/DPVControl

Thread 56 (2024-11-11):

[FEATURE] Move to PlatformIO - PRIO 8

n3roGit, 2024-11-11:
The Arduino plugin for VSCode is no longer actively maintained. To ensure ongoing support and future updates, we should transition the project to PlatformIO. However, this migration requires a significant amount of effort, and our initial attempts have not been successful.

Tasks:

Evaluate the current project setup with PlatformIO
Identify and resolve compatibility issues
Update documentation to reflect the new development environment
Test the project thoroughly to ensure stability after migration

Closed 2025-05-28.

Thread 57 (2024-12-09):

[BUG] "SOS Light" - PRIO 9

n3roGit, 2024-12-09:
If the front light is set to 100% power, only the beep will sound when the dead man's switch (SOS) is activated and the light will stay on permanently. If the light is turned off or the light output is less than 100%, it works perfectly.

Closed 2025-05-23.

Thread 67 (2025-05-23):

[FEATURE] "VESC Bridge" - PRIO 5

n3roGit, 2025-05-23:
It would be really great to use the uart communication between the esp32 and the vesc to control the vesc firmware.

Maybe it's possible to do it like this project.

https://github.com/A-Emile/VescBLEBridge

I don't know if it's possible to forward the vesc serial via Bluetooth AND control the vesc over the esp at the same time. Meybe we need a switch in the gui to change from serial bringe and back to normal mode.

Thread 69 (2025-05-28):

Implement new Charts

n3roGit, 2025-05-28:
https://github.com/danvk/dygraphs

Implement another type of graph. These must function entirely offline and support the following front-end capabilities:

* Mouse-hover tooltips for displayed data points
* Rendering of different data points with different units within the same graph
* High performance, even on an ESP32 platform

n3roGit, 2025-06-10:
fixed in https://github.com/BubTec/DPVControl/commit/85f23120080a29de4d30846aadfa7611cf1c5380

Closed 2025-06-10.

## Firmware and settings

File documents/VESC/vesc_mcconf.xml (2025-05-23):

<?xml version="1.0" encoding="UTF-8"?>
<MCConfiguration>
    <ConfigVersion>4</ConfigVersion>
    <pwm_mode>1</pwm_mode>
    <comm_mode>0</comm_mode>
    <motor_type>2</motor_type>
    <sensor_mode>0</sensor_mode>
    <l_current_max>110</l_current_max>
    <l_current_min>-1</l_current_min>
    <l_in_current_max>50</l_in_current_max>
    <l_in_current_min>-1</l_in_current_min>
    <l_in_current_map_start>1</l_in_current_map_start>
    <l_in_current_map_filter>0.005</l_in_current_map_filter>
    <l_abs_current_max>160</l_abs_current_max>
    <l_min_erpm>-4000</l_min_erpm>
    <l_max_erpm>140000</l_max_erpm>
    <l_erpm_start>1</l_erpm_start>
    <l_max_erpm_fbrake>300</l_max_erpm_fbrake>
    <l_max_erpm_fbrake_cc>1500</l_max_erpm_fbrake_cc>
    <l_min_vin>8</l_min_vin>
    <l_max_vin>57</l_max_vin>
    <l_battery_cut_start>44.2</l_battery_cut_start>
    <l_battery_cut_end>39</l_battery_cut_end>
    <l_battery_regen_cut_start>1000</l_battery_regen_cut_start>
    <l_battery_regen_cut_end>1100</l_battery_regen_cut_end>
    <l_slow_abs_current>0</l_slow_abs_current>
    <l_temp_fet_start>85</l_temp_fet_start>
    <l_temp_fet_end>100</l_temp_fet_end>
    <l_temp_motor_start>80</l_temp_motor_start>
    <l_temp_motor_end>95</l_temp_motor_end>
    <l_temp_accel_dec>0.15</l_temp_accel_dec>
    <l_min_duty>0.005</l_min_duty>
    <l_max_duty>0.95</l_max_duty>
    <l_watt_max>1800</l_watt_max>
    <l_watt_min>-1</l_watt_min>
    <l_current_max_scale>1</l_current_max_scale>
    <l_current_min_scale>1</l_current_min_scale>
    <l_duty_start>1</l_duty_start>
    <sl_min_erpm>150</sl_min_erpm>
    <sl_min_erpm_cycle_int_limit>1100</sl_min_erpm_cycle_int_limit>
    <sl_max_fullbreak_current_dir_change>10</sl_max_fullbreak_current_dir_change>
    <sl_cycle_int_limit>62</sl_cycle_int_limit>
    <sl_phase_advance_at_br>0.8</sl_phase_advance_at_br>
    <sl_cycle_int_rpm_br>80000</sl_cycle_int_rpm_br>
    <sl_bemf_coupling_k>600</sl_bemf_coupling_k>
    <hall_table__0>-1</hall_table__0>
    <hall_table__1>1</hall_table__1>
    <hall_table__2>3</hall_table__2>
    <hall_table__3>2</hall_table__3>
    <hall_table__4>5</hall_table__4>
    <hall_table__5>6</hall_table__5>
    <hall_table__6>4</hall_table__6>
    <hall_table__7>-1</hall_table__7>
    <hall_sl_erpm>2000</hall_sl_erpm>
    <foc_current_kp>0.1975</foc_current_kp>
    <foc_current_ki>21.04</foc_current_ki>
    <foc_f_zv>30000</foc_f_zv>
    <foc_dt_us>0.12</foc_dt_us>
    <foc_encoder_inverted>0</foc_encoder_inverted>
    <foc_encoder_offset>180</foc_encoder_offset>
    <foc_encoder_ratio>7</foc_encoder_ratio>
    <foc_sensor_mode>2</foc_sensor_mode>
    <foc_pll_kp>2000</foc_pll_kp>
    <foc_pll_ki>30000</foc_pll_ki>
    <foc_motor_l>0.00019746</foc_motor_l>
    <foc_motor_ld_lq_diff>8.629e-05</foc_motor_ld_lq_diff>
    <foc_motor_r>0.021</foc_motor_r>
    <foc_motor_flux_linkage>0.017834</foc_motor_flux_linkage>
    <foc_observer_gain>3.14e+06</foc_observer_gain>
    <foc_observer_gain_slow>0.05</foc_observer_gain_slow>
    <foc_observer_offset>-1</foc_observer_offset>
    <foc_duty_dowmramp_kp>50</foc_duty_dowmramp_kp>
    <foc_duty_dowmramp_ki>1000</foc_duty_dowmramp_ki>
    <foc_start_curr_dec>1</foc_start_curr_dec>
    <foc_start_curr_dec_rpm>2500</foc_start_curr_dec_rpm>
    <foc_openloop_rpm>1000</foc_openloop_rpm>
    <foc_openloop_rpm_low>0</foc_openloop_rpm_low>
    <foc_d_gain_scale_start>0.9</foc_d_gain_scale_start>
    <foc_d_gain_scale_max_mod>0.2</foc_d_gain_scale_max_mod>
    <foc_sl_openloop_hyst>0.1</foc_sl_openloop_hyst>
    <foc_sl_openloop_time_lock>0</foc_sl_openloop_time_lock>
    <foc_sl_openloop_time_ramp>0.1</foc_sl_openloop_time_ramp>
    <foc_sl_openloop_time>0.05</foc_sl_openloop_time>
    <foc_sl_openloop_boost_q>0</foc_sl_openloop_boost_q>
    <foc_sl_openloop_max_q>-1</foc_sl_openloop_max_q>
    <foc_hall_table__0>255</foc_hall_table__0>
    <foc_hall_table__1>44</foc_hall_table__1>
    <foc_hall_table__2>105</foc_hall_table__2>
    <foc_hall_table__3>70</foc_hall_table__3>
    <foc_hall_table__4>178</foc_hall_table__4>
    <foc_hall_table__5>9</foc_hall_table__5>
    <foc_hall_table__6>134</foc_hall_table__6>
    <foc_hall_table__7>255</foc_hall_table__7>
    <foc_hall_interp_erpm>500</foc_hall_interp_erpm>
    <foc_sl_erpm_start>2500</foc_sl_erpm_start>
    <foc_sl_erpm>4000</foc_sl_erpm>
    <foc_control_sample_mode>0</foc_control_sample_mode>
    <foc_current_sample_mode>0</foc_current_sample_mode>
    <foc_sat_comp_mode>2</foc_sat_comp_mode>
    <foc_sat_comp>0</foc_sat_comp>
    <foc_temp_comp>0</foc_temp_comp>
    <foc_temp_comp_base_temp>24.9</foc_temp_comp_base_temp>
    <foc_current_filter_const>0.1</foc_current_filter_const>
    <foc_cc_decoupling>0</foc_cc_decoupling>
    <foc_observer_type>0</foc_observer_type>
    <foc_hfi_amb_mode>0</foc_hfi_amb_mode>
    <foc_hfi_amb_current>60</foc_hfi_amb_current>
    <foc_hfi_amb_tres>15</foc_hfi_amb_tres>
    <foc_hfi_voltage_start>20</foc_hfi_voltage_start>
    <foc_hfi_voltage_run>4</foc_hfi_voltage_run>
    <foc_hfi_voltage_max>6</foc_hfi_voltage_max>
    <foc_hfi_gain>0.3</foc_hfi_gain>
    <foc_hfi_max_err>0.3</foc_hfi_max_err>
    <foc_hfi_hyst>0</foc_hfi_hyst>
    <foc_sl_erpm_hfi>3000</foc_sl_erpm_hfi>
    <foc_hfi_start_samples>5</foc_hfi_start_samples>
    <foc_hfi_obs_ovr_sec>0.001</foc_hfi_obs_ovr_sec>
    <foc_hfi_samples>1</foc_hfi_samples>
    <foc_offsets_cal_mode>1</foc_offsets_cal_mode>
    <foc_offsets_current__0>2048</foc_offsets_current__0>
    <foc_offsets_current__1>2048</foc_offsets_current__1>
    <foc_offsets_current__2>2048</foc_offsets_current__2>
    <foc_offsets_voltage__0>0</foc_offsets_voltage__0>
    <foc_offsets_voltage__1>0</foc_offsets_voltage__1>
    <foc_offsets_voltage__2>0</foc_offsets_voltage__2>
    <foc_offsets_voltage_undriven__0>0</foc_offsets_voltage_undriven__0>
    <foc_offsets_voltage_undriven__1>0</foc_offsets_voltage_undriven__1>
    <foc_offsets_voltage_undriven__2>0</foc_offsets_voltage_undriven__2>
    <foc_phase_filter_enable>0</foc_phase_filter_enable>
    <foc_phase_filter_disable_fault>1</foc_phase_filter_disable_fault>
    <foc_phase_filter_max_erpm>4000</foc_phase_filter_max_erpm>
    <foc_mtpa_mode>0</foc_mtpa_mode>
    <foc_fw_current_max>30</foc_fw_current_max>
    <foc_fw_duty_start>0.9</foc_fw_duty_start>
    <foc_fw_q_current_factor>0.02</foc_fw_q_current_factor>
    <foc_fw_ramp_time>0.2</foc_fw_ramp_time>
    <foc_speed_soure>1</foc_speed_soure>
    <foc_short_ls_on_zero_duty>0</foc_short_ls_on_zero_duty>
    <foc_overmod_factor>1</foc_overmod_factor>
    <sp_pid_loop_rate>6</sp_pid_loop_rate>
    <s_pid_kp>0.004</s_pid_kp>
    <s_pid_ki>0.004</s_pid_ki>
    <s_pid_kd>0.0001</s_pid_kd>
    <s_pid_kd_filter>0.2</s_pid_kd_filter>
    <s_pid_min_erpm>1100</s_pid_min_erpm>
    <s_pid_allow_braking>0</s_pid_allow_braking>
    <s_pid_ramp_erpms_s>25000</s_pid_ramp_erpms_s>
    <s_pid_speed_source>0</s_pid_speed_source>
    <p_pid_kp>0.025</p_pid_kp>
    <p_pid_ki>0</p_pid_ki>
    <p_pid_kd>0</p_pid_kd>
    <p_pid_offset>0</p_pid_offset>
    <p_pid_kd_proc>0.00035</p_pid_kd_proc>
    <p_pid_kd_filter>0.2</p_pid_kd_filter>
    <p_pid_ang_div>1</p_pid_ang_div>
    <p_pid_gain_dec_angle>0</p_pid_gain_dec_angle>
    <cc_startup_boost_duty>0.01</cc_startup_boost_duty>
    <cc_min_current>0.05</cc_min_current>
    <cc_gain>0.0046</cc_gain>
    <cc_ramp_step_max>0.04</cc_ramp_step_max>
    <m_fault_stop_time_ms>500</m_fault_stop_time_ms>
    <m_duty_ramp_step>0.02</m_duty_ramp_step>
    <m_current_backoff_gain>0.5</m_current_backoff_gain>
    <m_encoder_counts>8192</m_encoder_counts>
    <m_encoder_sin_amp>1</m_encoder_sin_amp>
    <m_encoder_cos_amp>1</m_encoder_cos_amp>
    <m_encoder_sin_offset>1.65</m_encoder_sin_offset>
    <m_encoder_cos_offset>1.65</m_encoder_cos_offset>
    <m_encoder_sincos_filter_constant>0.5</m_encoder_sincos_filter_constant>
    <m_encoder_sincos_phase_correction>0</m_encoder_sincos_phase_correction>
    <m_sensor_port_mode>0</m_sensor_port_mode>
    <m_invert_direction>0</m_invert_direction>
    <m_drv8301_oc_mode>0</m_drv8301_oc_mode>
    <m_drv8301_oc_adj>16</m_drv8301_oc_adj>
    <m_bldc_f_sw_min>3000</m_bldc_f_sw_min>
    <m_bldc_f_sw_max>35000</m_bldc_f_sw_max>
    <m_dc_f_sw>25000</m_dc_f_sw>
    <m_ntc_motor_beta>3380</m_ntc_motor_beta>
    <m_out_aux_mode>0</m_out_aux_mode>
    <m_motor_temp_sens_type>0</m_motor_temp_sens_type>
    <m_ptc_motor_coeff>0.61</m_ptc_motor_coeff>
    <m_ntcx_ptcx_res>10000</m_ntcx_ptcx_res>
    <m_ntcx_ptcx_temp_base>25</m_ntcx_ptcx_temp_base>
    <m_hall_extra_samples>1</m_hall_extra_samples>
    <m_batt_filter_const>45</m_batt_filter_const>
    <si_motor_poles>6</si_motor_poles>
    <si_gear_ratio>1</si_gear_ratio>
    <si_wheel_diameter>0.02</si_wheel_diameter>
    <si_battery_type>0</si_battery_type>
    <si_battery_cells>13</si_battery_cells>
    <si_battery_ah>24</si_battery_ah>
    <si_motor_nl_current>2.4</si_motor_nl_current>
    <motor_brand></motor_brand>
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

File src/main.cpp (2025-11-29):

/*
 * Copyright (C) 2024 Christoph Bubeck <christoph.bubeck@gmail.com>
 *
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
 * You should have received a copy of the GNU General Public License
 * along with this program.  If not, see <http://www.gnu.org/licenses/>.
 */

// DPV Control - Main firmware for ESP32-based dive propulsion vehicle
// Test release notes generation
#include <Arduino.h>

#include "main.h"

#include "constants.h"
#include "Blinker.h" 
#include "BlinkSequence.h" 
#include "log.h"
#include "beep.h"
#include "other.h"
#include "button.h"
#include "datalog.h"
#include "webserver.h"  // Include webserver header
#include "data_upload.h" // Include data upload header
#include "settings.h" // Include DPV settings system
#include "vesc_task.h" // Include VESC task
#include <LittleFS.h> // For settings storage

// Global variables
int leakSensorFront = 0;        // Current front leak sensor state (0=OK, 1=LEAK)
int leakSensorBack = 0;         // Current back leak sensor state (0=OK, 1=LEAK)
int leakAlarmPersistent = 0;    // Persistent leak alarm flag (survives reboots, 0=OK, 1=ALARM)
int leakAlarmFrontPersistent = 0; // Persistent front sensor alarm (0=OK, 1=FRONT_ALARM)
int leakAlarmBackPersistent = 0;  // Persistent back sensor alarm (0=OK, 1=BACK_ALARM)
int loopCount = 0;              // Counter for main loop iterations
int NormalLogOutputIntervall = 1000*10;  // Normal logging interval (10 seconds)

DHTesp dhtSensor;  // Temperature and humidity sensor

/**
 * System initialization
 * Sets up all hardware components and subsystems
 */
void setup() {
  // Configure GPIO pins
  pinMode(PIN_LEFT_BUTTON, INPUT);      // Left control button
  pinMode(PIN_RIGHT_BUTTON, INPUT);     // Right control button
  pinMode(PIN_LEAK_FRONT, INPUT_PULLUP); // Front leak sensor with pullup
  pinMode(PIN_LEAK_BACK, INPUT_PULLUP);  // Back leak sensor with pullup
  pinMode(PIN_LAMP, OUTPUT);            // Main LED lamp
  pinMode(PIN_BEEP, OUTPUT);            // Buzzer/beeper

  // Initialize serial communication
  Serial.begin(115200);

  // Keep essential startup messages unconditional for debugging
  log("Booting started...!");

  // Initialize LittleFS first for settings
  if (!LittleFS.begin(true)) {
    log("LittleFS initialization failed!");
  } else {
    log("LittleFS initialized for settings");
  }
  
  // Initialize settings system BEFORE hardware that depends on settings
  initializeSettings();
  loadSettings();

  // Initialize button control system
  buttonSetup();

  // Setup DHT22 sensor with error handling
  log("Initializing DHT22 sensor...");
  dhtSensor.setup(PIN_DHT, DHTesp::DHT22);
  delay(2000); // Give DHT sensor time to stabilize
  
  TempAndHumidity data = dhtSensor.getTempAndHumidity();
  if (isnan(data.temperature) || isnan(data.humidity)) {
    log("DHT22 sensor not ready, using default values");
    log("Temp: 20.0°C (default)");
    log("Humidity: 50.0% (default)");
  } else {
    log("Temp: " + String(data.temperature, 2) + "°C");
    log("Humidity: " + String(data.humidity, 1) + "%");
  }
  log("---");

  // Initialize hardware subsystems (now with settings available)
  // Must be initialized BEFORE startVescTask because vescTask might use them (e.g. battery level updates)
  motorSetup();     // Motor control logic
  ledLampSetup();   // Main LED lamp PWM control
  ledBarSetup();    // LED status bar (now with proper settings)
  batterySetup();   // Battery monitoring

  // Start VESC communication task on Core 0
  // This handles all UART communication with the motor controller
  startVescTask();
  
  // Initialize datalogger (will re-initialize LittleFS if needed)
  datalogSetup();

  // Load persistent leak alarm state
  loadPersistentLeakAlarm();
  
  // Debug current alarm states at startup
  debugLeakAlarmStates();

  // Initialize webserver on Core 0
  setupWebserver();

  // Booting finished - keep unconditional for debugging
  log("Booting finished!");
  beep("1");
}

/**
 * Main system loop
 * Handles all real-time operations and system monitoring
 */
void loop() {
  long loopStart = millis();
  loopCount++;

  // Core system operations
  buttonLoop();           // Process button inputs and actions
  motorLoop();           // Update motor control and speed
  checkForLeak();        // Monitor leak sensors
  // GetVESCValues();    // REMOVED: Now handled by background task
  logVehicleState();     // Log current system state
  FromTimeToTimeExecution(); // Periodic maintenance tasks
  beepLoop();            // Handle beeper sequences
  ledLampLoop();         // Update LED lamp states
  ledBarLoop();          // Update LED bar states (handles requests from other cores)
  datalogLoop();         // Data logging operations
  
  // Update battery display on Core 1 (Main Loop)
  // This ensures LED hardware access is thread-safe and consistent
  updateBatteryDisplay();

  // Performance monitoring
  long loopEnd = millis();
  long diff = loopEnd-loopStart;
  if (diff > 30){
    log("Loop took", diff, true);  // Warn if loop takes too long
  }
  
  delay(1);  // Small delay to prevent watchdog issues
}

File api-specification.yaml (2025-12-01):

openapi: 3.0.0
info:
  title: DPVControl API
  description: API for controlling and monitoring the Diver Propulsion Vehicle (DPV)
  version: 1.2.7
  contact:
    name: DPV Control Project
    url: https://bubtec.de/2024/10/29/diy-scooter-dpv-mit-aquazepp-und-dpvcontrol/
  license:
    name: MIT
    url: https://opensource.org/licenses/MIT

servers:
  - url: http://4.3.2.1
    description: DPV Control Device (Captive Portal)
  - url: http://192.168.4.1
    description: DPV Control Device (AP Mode)

tags:
  - name: Status
    description: System status and real-time data
  - name: Data
    description: Sensor data and logging
  - name: Settings
    description: Device configuration
  - name: Control
    description: Motor and lamp control
  - name: Trip Log
    description: Historical trip data

paths:
  /api/status:
    get:
      tags:
        - System
      summary: Get system status
      description: Returns current system status information including operational status, uptime, and sensor data
      responses:
        '200':
          description: System status information
          content:
            application/json:
              schema:
                type: object
                properties:
                  status:
                    type: string
                    description: Overall system status
                    example: "ok"
                  uptime:
                    type: integer
                    description: Current system uptime in milliseconds
                    example: 3654000
                  totalUptime:
                    type: integer
                    description: Total device operating time in seconds
                    example: 12345
                  dataPoints:
                    type: integer
                    description: Number of data points in current recording buffer
                    example: 120
                  motor:
                    type: boolean
                    description: Whether the motor is currently running
                    example: false
                  lamp:
                    type: boolean
                    description: Whether the lamp is currently on
                    example: true
                  beeper:
                    type: boolean
                    description: Whether the beeper is currently enabled
                    example: true
                  waterSensorFront:
                    type: boolean
                    description: Front water sensor state (true if leak detected)
                    example: false
                  waterSensorBack:
                    type: boolean
                    description: Back water sensor state (true if leak detected)
                    example: false
                  leftButton:
                    type: boolean
                    description: Left button state (true if pressed)
                    example: false
                  rightButton:
                    type: boolean
                    description: Right button state (true if pressed)
                    example: false
                  lampLevel:
                    type: integer
                    description: Current lamp brightness level
                    example: 2
                  beeperEnabled:
                    type: boolean
                    description: Whether the beeper is enabled
                    example: true
                  erpm:
                    type: number
                    description: Current motor speed in electrical RPM
                    example: 12500
                  batteryVoltage:
                    type: number
                    description: Current battery voltage in Volts
                    example: 48.2
                  motorTemperature:
                    type: number
                    description: Motor temperature in Celsius
                    example: 42.5
                  mosfetTemperature:
                    type: number
                    description: MOSFET temperature in Celsius
                    example: 38.2
                  current:
                    type: number
                    description: Average input current in Amperes
                    example: 15.3
                  motorCurrent:
                    type: number
                    description: Average motor current in Amperes
                    example: 20.1
                  dutyCycle:
                    type: number
                    description: Current duty cycle (0.0 to 1.0)
                    example: 0.75
                  temperature:
                    type: number
                    description: Ambient temperature in Celsius from DHT sensor
                    example: 22.5
                  humidity:
                    type: number
                    description: Ambient humidity percentage from DHT sensor
                    example: 65.2
                  beeperActive:
                    type: boolean
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

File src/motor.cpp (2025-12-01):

#include "motor.h"
#include "constants.h"
#include "beep.h"
#include "log.h"
#include "ledBar.h"
#include "button.h"
#include "ledLamp.h"
#include "battery.h"
#include "settings.h"
#include "vesc_task.h" // Include VESC task interface

/**
*
* Methods that control motor and speed.
*/

MotorState motorState = standby;
bool remoteControlActive = false; // Flag for remote control override
const bool HAS_MOTOR = true;//Indicates that we have an actual motor plugged in.
bool reverseModeActive = false;    // Reverse drive mode flag

/*
*  CONSTANTS
*/
const int SPEED_STEPS = 10;                  //Number speed steps
const int STANDBY_DELAY_US = 60 /*s*/ * 1000 * 1000;  // Time until the motor goes into standby.
const int BATTERY_POWER_MAX = 40; // in Ampere
const unsigned long MAX_DELTA_US = 30/*microseconds*/ * 1000; //Maximum time from last run to consider for smooth acceleration
const double MIN_SPEED_PERCENT = 0.38; //Speed on lowest setting in percent of max.
const double MIN_SPEED_SOFT = 0.1; //Minumum % we sent to the motor during soft acceleration. 
const double MAX_SPEED_RPM = 15800; //Maximum speed in rpm. Speed of 100% 
const int SPEED_UP_TIME_US = 3/*s*/ * 1000 * 1000;    //time we want to take to  speed the motor from 0 to  full power.
const int SPEED_DOWN_TIME_US = 500/*ms*/ * 1000;  //time we want to take to  speed the motor from full power to 0.
const long MAX_TIME_OVERLOADED = 5/*s*/ * 1000; //Maximum time in ms that we overload the battery before lowering motor power.

const float JAM_MIN = 0.2; //The minumum speed in % for jam detection
const float JAM_DETECTION_THRESHOLD = 0.5; //Percentage of target speed
//that we must be under for a jam to be detected.

/*
* VARIABLES 
*/
double currentMotorSpeed = 0;           //Speed the motor is currently running at(0.0-1.0)
int currentMotorStep = 3;//The current speed setting. stays the same, even if motor is turned off. 
//Goes from 1(very slow) to SPEED_STEPS(max)
int overloadSpeedThrottle = NEVER; //Either NEVER or the maximum speed setting before we would overload the battery.
unsigned long currentMotorTime = micros();  //Time in microseconds when we last changed the currentMotorSpeed
double targetMotorSpeed = 0.0;  //The desired motor speed. In Percent of max-power.
double lastTargetMotorSpeed = targetMotorSpeed;
double lastPrintedMotorSpeed = -1;
unsigned long overLoadedSince = NEVER; //microsecond timestamp.
unsigned long lastStandbyBeepTime = 0;


void motorSetup(){
  // VESC initialization is now handled in vescTask (vesc_task.cpp)
  log("Motor setup complete (VESC handled by task)");
}

void toggleReverseMode(){
  reverseModeActive = !reverseModeActive;
  if (reverseModeActive) {
    log("Reverse mode enabled", 0);
    beep("2"); // Long beep for reverse enabled
  } else {
    log("Reverse mode disabled", 0);
    beep("1"); // Short beep for reverse disabled
  }
  // Force LED bar to refresh to show or hide reverse indication
  forceRefreshLedBar();
  setBarSpeed(currentMotorStep);
}

bool isReverseModeActive(){
  return reverseModeActive;
}

void speedUp(){
  int maxSteps = getSpeedSteps();
  if (currentMotorStep == maxSteps){
    beep("1");
  }else if(overloadSpeedThrottle != NEVER 
    &&currentMotorStep+1>=overloadSpeedThrottle){
    log("No speedup because overloaded.");
    beep("111");
  }else{
    log("speed up", currentMotorStep);
    currentMotorStep++;
  }
  setBarSpeed(currentMotorStep);
}

void speedDown(){
  if (currentMotorStep > 1){
    currentMotorStep--;
  }else{
    beep("1");
  }
  log("speed down", currentMotorStep);
  setBarSpeed(currentMotorStep);
}

// Function to control standby mode
void controlStandby() {
  if (motorState == off)  {
    unsigned long standbyDelayUs = (unsigned long)getStandbyDelay() * 1000UL * 1000UL; // Convert seconds to microseconds
    if (lastActionTime + standbyDelayUs < micros()) {
      standBy();
    }
  }
  
  if (motorState == standby && micros() - lastStandbyBeepTime >= (1 * 60 * 1000000)) {
    beep("1"); 
    log("still in standby");
    lastStandbyBeepTime = micros(); 
  }
}

void wakeUp(){
  motorState = off;
  lastActionTime = micros();
  log("leaving standby");
  beep("2");
  setBarSpeed(currentMotorStep);
}

void standBy(){
  log("going to standby");
  motorState = standby;
  lastStandbyBeepTime = micros();//Avoid the regular beep to be triggered just hwen going to standby
  beep("11");
  setBarStandby();
}

/**
* Slowly changes the motor speed to targetMotorSpeed.
*
**/
void setSoftMotorSpeed() {
  float timePassedSinceLastChange = min(micros() - currentMotorTime, MAX_DELTA_US);
  double lastMotorSpeed = currentMotorSpeed;
  
  // Get timing settings from configuration
  unsigned long speedUpTimeUs = (unsigned long)getSpeedUpTime() * 1000UL; // Convert ms to microseconds
  unsigned long speedDownTimeUs = (unsigned long)getSpeedDownTime() * 1000UL; // Convert ms to microseconds
  
  if (currentMotorSpeed < targetMotorSpeed) {
    //Speed up
    float maxChange = timePassedSinceLastChange / (float)speedUpTimeUs;
    currentMotorSpeed += maxChange;
    currentMotorSpeed = 
      //Do not go lower than minimal setting.
      max(MIN_SPEED_SOFT, 
      //Do not overshoot the actual targetMotorSpeed
      min(currentMotorSpeed, targetMotorSpeed));
  } else if(currentMotorSpeed > targetMotorSpeed) {
    //Speed down
    float maxChange = timePassedSinceLastChange / (float)speedDownTimeUs;
    currentMotorSpeed -= maxChange;
    currentMotorSpeed = max(currentMotorSpeed, targetMotorSpeed);
  }
  double effectiveSpeed = currentMotorSpeed * getMaxSpeedRpm();
  // Apply direction based on reverse mode
  if (reverseModeActive) {
    effectiveSpeed = -effectiveSpeed;
  }
  
  // Use the thread-safe function to set target RPM in the VESC task
  setVescTargetRpm(effectiveSpeed);
  
  currentMotorTime = micros();

  if(EnableDebugLog && abs(currentMotorSpeed - lastPrintedMotorSpeed) >= 0.01){
    log("eRPM: " + String(effectiveSpeed, 0) + " (" + String(currentMotorSpeed*100, 0) + "%)");
    lastPrintedMotorSpeed = currentMotorSpeed;
  }
}
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

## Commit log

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2023-07-06 Testing LED Control
    Its not working at the moment. conflict with servo.h
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2023-11-12 use correct value for HIGH->LOW for the button. This was the reason we had always negative click-codes. Also why we had to wait for the longClick-time.
    [battery.ino, button.ino]
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2023-11-13 moved VescUart and fixed the link. It was pointing at the wrong repo!!
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2023-11-19 detect overload then after 5s force a speeddown prevent speed from going higher remove throttle once overload ends.
    [ledLamp.ino]
2023-11-19 reset overLoadedSince when doing a speeddown to prevent running into that branch all the time, until power actually goes down.
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2023-11-20 changed leak warning code
    [beep.ino]
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2023-11-21 fixen vscode deploy
    [partitions.csv]
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2023-11-21 fix calculation of speed from speed steps. old calculation did not take into account, that we do not have a speed 0.
    [motor.cpp]
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2023-11-21 reset lastStandbyBeepTime when entering standby to avoid an extra beep. Also moved the code to motor.
    [beep.cpp, motor.cpp, other.cpp]
2023-12-30 fixed set serial do not use getter
    [motor.cpp]
2023-12-30 prevent entering standup after leaving cruise control
    [motor.cpp]
2024-01-06 fixed led link sos
    [ledLamp.cpp]
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2024-01-15 fixen dafeult led long blink
    time and if
    [ledLamp.cpp]
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2024-01-27 prevent entering standby right after leaving turbo.
    [motor.cpp]
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2024-09-29 issues/55
    fixed https://github.com/n3roGit/DPVControl/issues/55
    and some beep codes.
    [button.ino, motor.cpp]
2024-09-29 issues/40
    set start speed to lvl 3
    https://github.com/n3roGit/DPVControl/issues/40
    [motor.cpp]
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2025-05-25 fixed after lib update
    Ich habe die Fehler in der ledLamp.cpp Datei behoben. Das Problem lag daran, dass in der neuen ESP32 Arduino Core Version 3.0 die Funktionen ledcSetup und ledcAttachPin entfernt wurden und durch die neue API-Funktion ledcAttach ersetzt wurden.
    Die wichtigsten Änderungen sind:
    ledcSetup(LEDchannel, LEDfrequency, LEDresolution) und ledcAttachPin(PIN_LAMP, LEDchannel) wurden durch einen einzigen Aufruf ledcAttach(PIN_LAMP, LEDfrequency, LEDresolution) ersetzt.
    Bei ledcWrite wird jetzt direkt der Pin statt des Kanals angegeben: ledcWrite(PIN_LAMP, brightness) statt ledcWrite(LEDchannel, brightness).
    Diese Änderungen entsprechen der offiziellen Migrationsdokumentation fü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
    [ledLamp.cpp]
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2025-05-26 fixed session dropdown loading chart
    [webserver.cpp]
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2025-05-26 maybe fixing saving settings problem
    [webserver.cpp]
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2025-05-27 fix time windows slider
    [webserver.cpp]
2025-05-27 replace rpm with erpm
    [api-specification.yaml, data_upload.cpp, datalog.cpp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]
2025-05-27 fix depricated warning
    'bool ArduinoJson::V741PB22::JsonDocument::containsKey(TChar*) const [with TChar = const char]' is deprecated: use doc["key"].is<T>() instead [-Wdeprecated-declarations]
    [webserver.cpp]
2025-05-27 fix Front Lamp Control slider
    [webserver.cpp]
2025-05-27 fix time slider direction and session time to display
    [webserver.cpp]
2025-05-27 fix remote light slider
    [webserver.cpp]
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2025-05-28 fix ledbarled to display
    [beep.cpp, ledBar.cpp, ledLamp.cpp]
2025-05-28 fix total runtime loss
    [datalog.cpp]
2025-05-28 fix remote control led
    [webserver.cpp]
2025-05-28 feat: Display actual brightness values in front lamp remote control
    - Replace hardcoded level descriptions with dynamic brightness values
    - Add updateLampLevelInterface() function for dynamic radio button generation
    - Integrate lamp level interface updates into settings loading/saving
    - Enable remote control interface after system initialization
    - Show actual PWM values (0-255) instead of generic "Low/Medium/High" labels
    Fixes lamp remote control interface to reflect configured brightness settings.
    [webserver.cpp]
2025-05-28 fix: LED bar now correctly displays standby mode after boot animation
    - Initialize lastActionTime in buttonSetup() to prevent immediate standby timeout
    - Add explicit LED bar update when transitioning from standby to off state
    - Export currentMotorStep in motor.h for access from button.cpp
    - Ensure LED bar shows standby indication after Knight Rider boot sequence
    Fixes issue where LED bar remained dark after boot instead of showing standby status.
    [button.cpp]
2025-05-28 Fix LED strip color conflicts in battery display
    - Separate Knight Rider animation to only affect Strip 1
    - Preserve Strip 2 (battery display) during boot animation
    - Optimize initialization order: battery display first, then standby
    - Prevent color mixing between different display functions
    [ledBar.cpp, other.cpp]
2025-05-28 fix export all csv
    [api-specification.yaml, webserver.cpp]
2025-05-28 fix parralel knight rider light
    [ledBar.cpp]
2025-05-28 fix: resolve battery display issue after knight rider animation
    - Fix LED strip initialization order in ledBarSetup()
    - Prevent setBarStandby from resetting battery cache
    - Ensure battery display properly updates on Strip 2 after startup
    - Strip 1 and Strip 2 now operate independently without cache conflicts
    [ledBar.cpp, webserver.cpp]
2025-05-29 fix: remove 50-session limit in delete all sessions API
    - Replace listSessionFiles() with direct directory iteration
    - Now deletes ALL session files instead of just first 50
    - Improves file handle management during deletion process
    - Fixes issue where sessions beyond index 50 were not deleted
    [webserver.cpp]
2025-05-29 Fix LED bar overlay issues and boundary violations
    - Add boundary checks for all LED strip access operations
    - Implement safe LED update mechanism with concurrency protection
    - Fix setBarSpeedCruise() mixed setBar/setPixelColor operations
    - Correct Knight Rider animation strip 2 index calculations
    - Add comprehensive LED strip boundary validation
    - Prevent race conditions between different LED update functions
    Resolves LED color bleeding and overlay issues in battery display
    [ledBar.cpp]
2025-05-29 Fix intermittent LED strip initialization issues with explicit clearing and timing delays
    [ledBar.cpp]
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2025-05-29 Add motor data to status webpage and API
    - Extended /api/status API endpoint with motor data (ERPM, temperature, voltage, current)
    - Added motor status section to info.html with 8 new data points
    - Updated API documentation with new status endpoint fields
    - Fixed issue where ERPM values weren't being shown on the status page
    [api-specification.yaml, data_upload.cpp, webserver.cpp]
2025-06-01 feat: Use Total Uptime as primary time reference in CSV exports
    - Replace confusing 1970 timestamps with Total Uptime (s) as first column
    - Remove problematic Unix timestamp conversion from millis()
    - Update both JavaScript and server-side CSV export functions
    - Update API documentation to reflect new CSV format
    - Total Uptime provides clear session timeline in seconds since ESP32 boot
    Fixes timestamp confusion while preserving all sensor data.
    eRPM communication issue remains separate problem to investigate.
    [api-specification.yaml, webserver.cpp]
2025-06-01 Implement the VESC_VALUES_INTERVAL timing to prevent UART overload
    unsigned long currentTime = millis();
    if (currentTime - lastVescUpdate < VESC_VALUES_INTERVAL) {
    return; // Skip update if interval hasn't passed
    }
    [other.cpp]
2025-06-01 Fix: Implement streaming CSV export to prevent ESP32 memory crashes
    - Replace 400KB string-based CSV export with streaming technology
    - Support sessions with 10,000+ data points without memory issues
    - Auto-detect large sessions and use streaming (>100 points)
    - Fix eRPM readings with proper VESC UART timing
    - Use Total Uptime as primary time reference instead of 1970 timestamps
    - Remove duplicate function definition causing compilation errors
    [api-specification.yaml, webserver.cpp]
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2025-06-02 feat(tests): Enhance test coverage and structure
    - Add comprehensive hardware tests:
    - Water sensors (front/back)
    - DHT22 temperature/humidity
    - LED bar (20 LEDs, 2 sections)
    - Front lamp PWM
    - Click codes
    - Motor control
    - Beeper
    - Improve test architecture:
    - Implement Arrange-Act-Assert pattern
    - Add helper methods for common assertions
    - Better error handling and messages
    - More realistic test data
    - Edge case coverage
    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
    [mock_hardware.cpp, webserver.cpp]
2025-06-02 Fix test build: remove duplicate mock_hardware.h, correct function names, and link Unity framework
    [mock_hardware.cpp]
2025-06-03 Fix native test stability: robust String mock, safe JSON serialization, all API tests pass
    [mock_hardware.cpp]
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2025-06-05 Fix type conflict for getMaxTimeOverloaded() (use long everywhere)
    [motor.cpp]
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2025-06-05 Fix: Make button state variables available in webserver.cpp for status API
    [beep.cpp, webserver.cpp]
2025-06-05 Fix: Load saved settings (e.g. beeper) after boot to respect user configuration
    [main.cpp]
2025-06-05 Fix API: Return error message in JSON when saving settings fails
    [webserver.cpp]
2025-06-05 Fix battery level calculation: Use configurable cellsInSeries from settings
    [battery.cpp]
2025-06-05 Fix status display: Add uptime data to status API and fix battery calculation
    - Fix battery level: Use configurable cellsInSeries from settings instead of hardcoded value
    - Fix uptime display: Add uptime and totalUptime fields to /api/status endpoint
    - Status page now correctly shows battery level, current uptime, and total uptime
    - All tests pass, compilation successful
    [webserver.cpp]
2025-06-05 Add comprehensive test suite for API and status data validation
    - Add API endpoint tests with JSON validation
    - Add status API uptime field validation (prevents missing uptime bug)
    - Add mock system for hardware simulation in tests
    - Add PowerShell test runner script
    - Update API documentation version to 1.0.1
    - Tests prevent regressions like missing uptime/totalUptime fields
    Tests can be run with: ./run_all_tests.ps1
    [api-specification.yaml, mock_hardware.cpp]
2025-06-05 Fix GitHub Actions linting errors: Remove trailing whitespace and update cpplint config
    - Remove trailing whitespace from src/battery.cpp and src/webserver.cpp (309 total issues)
    - Add comprehensive cpplint filters for Arduino/ESP32 project compatibility
    - Update super-linter configuration with increased line length (120 chars)
    - Add .cpplint config file for consistent local/CI linting
    - All tests pass and ESP32 compilation successful
    [battery.cpp, webserver.cpp]
2025-06-05 Fix GitHub Actions linter configuration and add copyright headers
    - Temporarily disable strict C++ linting due to 450+ formatting issues
    - Add copyright headers to battery.cpp and webserver.cpp
    - Include <algorithm> header for min/max functions
    - Disable JS/CSS/HTML linting for embedded code strings
    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
    [battery.cpp, webserver.cpp]
2025-06-05 Fix clang-format issues and improve code formatting
    - Break long sendHttpResponse lines for better readability
    - Split long string concatenations in beeper API
    - Improve captive portal detection formatting
    - Add .clang-format config with Arduino/ESP32 settings
    - Set ColumnLimit to 100 chars for better balance
    - Disable clang-format in super-linter configuration
    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
    [webserver.cpp]
2025-06-05 Fix PlatformIO configuration and GitHub Actions for releases
    - Add missing [platformio] section with default_envs = esp32dev
    - Fix GitHub Actions to explicitly build ESP32 environment
    - Correct firmware file paths for release artifacts
    - Fix version variable reference in commit message
    - Releases should now work correctly again
    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
2025-06-06 fix front lamp gui
    Move LED Frequency setting from LED Bar to Front Lamp section on settings page
    Remove lamp level 0 radio button from remote UI; ON/OFF now only via toggle button
2025-06-06 Fix lamp brightness percentage to PWM conversion; 100% now correctly maps to PWM 255
2025-06-06 Add runtime settings update mechanism; lamp and LED bar settings now apply immediately without reboot
    - Remove hardcoded LED frequency, now reads from settings
    - Add applyLampSettings() to update PWM frequency at runtime
    - Add applyLedBarSettings() to refresh LED displays with new settings
    - Call both functions after settings save in webserver
    - No reboot required for lamp/LED bar configuration changes
    [ledBar.cpp, ledLamp.cpp, webserver.cpp]
2025-06-06 Fix default settings values in HTML and add defaults to tooltips; enable runtime settings apply for default restore
    [webserver.cpp]
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2025-06-09 feat: Display real eRPM values instead of divided by 100
    - Changed chart label from "RPM (÷100)" to "eRPM"
    - Updated axis title and data processing to show actual eRPM values
    - Updated CSV export header to reflect correct unit
    - All tests passing, ESP32 compilation successful
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2025-06-09 fix graph time window
    const windowSize = Math.floor(100 * currentZoomLevel); // Zoom bestimmt Größe
    const sliderPercent = timeSliderValue / 100.0; // Position 0-100%
    const maxStartIndex = Math.max(0, totalDataLength - windowSize);
    const startIndex = Math.floor(maxStartIndex * sliderPercent); // Echter Start
2025-06-09 Fix CSV export 404 error and time window positioning
    - Update CSV headers to include all LogdataRow fields
    - Fix time slider labels to use totalUptime instead of timestamp
    - Improve time window navigation logic for better UX
    - Update API documentation to version 1.1.1
    - All tests passing, backward compatible"
    [api-specification.yaml, webserver.cpp]
2025-06-09 Fix CSV export path handling for session files
    - Fixed generateSessionCsvData() to use correct /datalog/ path prefix
    - Fixed streamSessionCsvData() to use correct /datalog/ path prefix
    - Added proper path logging for debugging
    - Updated API version to 1.1.3
    - CSV export now works for session files in /datalog/ directory
    [test_clean.csv]
2025-06-09 Remove broken time window controls, prepare for native Chart.js zoom
    - Removed non-functional time slider and zoom buttons
    - Removed updateTimeWindow(), zoomChart(), updateChart() functions
    - Simplified chart data loading to show all data points
    - Added placeholder for future Chart.js zoom plugin integration
    - Updated UI with native zoom instructions (mouse wheel + drag)
    - Improved chart performance by removing windowing logic
2025-06-09 Add Chart.js zoom plugin 2.2.0 with native zoom functionality
    - Downloaded chartjs-plugin-zoom v2.2.0 (15.2 KB)
    - Added plugin script to index.html
    - Activated zoom configuration in chart options
    - Enabled wheel zoom, pan, and double-click reset
    - X-axis focused zoom for time-based navigation
    - Updated info text with zoom instructions
    - All data points loaded for full session visualization
2025-06-09 Change LED logging from level (0-4) to brightness percentage (0-100%)
    - Add getLedBrightnessPercent() function to convert PWM (0-255) to percent (0-100%)
    - Replace LogdataRow.ledState with ledBrightness for percentage storage
    - Update all CSV headers from "LED State" to "LED Brightness (%)"
    - Change chart from boolean Y-axis to percent Y-axis for LED data
    - Update API field from ledState to ledBrightness with proper documentation
    - Increment API version from 1.1.3 to 1.2.0
    - Fix test data and delta compression to use new field name
    Now LED chart shows actual brightness percentage instead of confusing level numbers
    [api-specification.yaml, datalog.cpp, datalog.h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]
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2025-06-10 Fix chart time display and live session auto-refresh
    - Fix time axis to show session-relative time instead of total uptime
    - Add auto-refresh for chart data in live sessions
    - Implement auto-zoom to show latest data automatically
    - Update API version to 1.2.2
    - Add debugging console output for session time ranges
    Fixes: Chart showing wrong time scale and requiring manual zoom for latest data
    [api-specification.yaml]
2025-06-10 Fix live session time display using RAM buffer data
    - Use /api/data endpoint for live sessions instead of session files
    - Fix time axis to show accurate session duration from current boot
    - Add auto-refresh and auto-zoom for live data visualization
    - Prevent showing old data from previous ESP32 boots
    - Update API version to 1.2.3
    - Add comprehensive debugging output for time calculations
    Fixes: Chart showing incorrect time range due to session file containing old boot data
    [api-specification.yaml]
2025-06-10 Fix chart time display and remove beeper log spam
    - Chart now uses first available datapoint as time reference instead of system boot
    - This correctly shows the time span of available data in live sessions
    - Removed spam logging "Beeper disabled, ignoring leak beep request"
    - Clean serial output for better debugging experience
    - API version updated to 1.2.4
    [api-specification.yaml, beep.cpp]
2025-06-10 Fix chart time axis to display actual session duration
    - Changed X-axis to linear scale with explicit x,y coordinates
    - Fixed issue where chart showed 8 seconds for 0.1-second sessions
    - Chart now uses real totalUptime values instead of data point indices
    - Added debugging output for time range calculations
2025-06-10 feat: Add comprehensive test infrastructure to prevent calculation bugs
    - Fixed JavaScript chart time axis to use actual totalUptime values instead of data point indices
    - Added comprehensive test runner script with quality gates and detailed reporting
    - Enhanced API tests to verify uptime field presence (prevents missing totalUptime bugs)
    - Improved mock implementations for better test coverage
    - All tests passing: 9 test cases across API validation and ESP32 compilation
    [mock_hardware.cpp]
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2025-06-10 Fix: Switch to ncipollo/release-action and remove problematic cleanup steps
    - Remove failing temp file cleanup that caused exit code 1
    - Switch from softprops/action-gh-release@v2 to ncipollo/release-action@v1 to avoid Node.js file handle bug
    - Remove unnecessary debug and file preparation steps
    - Keep ubuntu-22.04 runner for stability
    [battery.cpp]
2025-06-15 feat: Implement embedded webfiles system to prevent data loss
    - Add embed_webfiles.py script for automatic pre-build file embedding
    - Create embedded webserver system with PROGMEM storage
    - Move web files from /data to /upload directory
    - Add automatic C++ header generation with registry system
    - Update webserver to serve from embedded files with SPIFFS fallback
    - Add src/generated/ to .gitignore for auto-generated files
    - Update API documentation to version 1.2.6
    - Eliminate need for SPIFFS uploads that overwrite persistent data
    Benefits:
    - No more data loss during web file updates
    - Automatic embedding during compilation
    - Faster file serving from program memory
    - Better version control f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
    [api-specification.yaml, webserver.cpp]
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2025-06-15 fix duty cycle and erpm shown in graph
    [api-specification.yaml, webserver.cpp]
2025-06-15 fix uptime in chart
    [webserver.cpp]
2025-06-15 fix: Remove duplicate key in .clang-format and add EmbeddedFile fallback definitions
    [webserver.cpp]
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2025-06-16 "fix: Increase session dropdown limit from 50 to 100 and improve sorting
    - Fixed bug where sessions beyond #50 were not visible in web GUI dropdown
    - Current session is now always displayed first regardless of session count
    - Improved sorting to show newest sessions first after current session
    - Increased listSessionFiles array from 50 to 100 sessions
    - Only 800 bytes additional RAM usage with significant UX improvement"
    [datalog.cpp, webserver.cpp]
2025-06-16 "fix: Reset session numbering to 0001 after delete-all operation
    - Fixed issue where session numbers continued incrementing after delete-all
    - Sessions now restart from session_0001.bin after delete-all operation
    - Added automatic new session creation after successful bulk deletion
    - Improves user experience with predictable session numbering"
    [webserver.cpp]
2025-06-16 feat: Enhanced leak detection with dual sensors and persistent alarm
    - Add separate front/back leak sensors with individual logging
    - Implement persistent leak alarm that survives reboots
    - Add /api/leak-alarm/reset endpoint for manual alarm clearing
    - Enhanced beeping patterns for different alarm states
    - Extended CSV export and JSON API with new leak fields
    - Optimize RAM usage for expanded LogdataRow structure
    - Remove legacy leakSensorState from LogdataRow struct
    [beep.cpp, datalog.cpp, datalog.h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]
2025-07-01 Phase 1: Extract HTTP request parsing from handleClient method
    - Add HttpRequest struct for structured request data
    - Implement parseHttpRequest() function to extract method, path, host, etc.
    - Replace 46 lines of inline parsing logic in handleClient with clean function call
    - Maintain full backward compatibility with existing routing logic
    - All functionality preserved, builds and tests pass
    handleClient method reduced from 808 lines to 762 lines (-46 lines)
    Next phase will extract API handlers to dedicated functions.
    [webserver.cpp]
2025-09-01 Core Pinning
    feat(rt): move datalogger to Core 0; keep motor/buttons/LED/beeper on Core 1
    rationale: reduce jitter on time-critical paths; web + logging isolated
    tests: run_all_tests.ps1 passed; esp32 build ok
    [datalog.cpp]
2025-09-01 Update ledBar.cpp
    ix(ledbar): add FreeRTOS mutex + show() rate limit to prevent color glitches
    details: guard concurrent updates across cores; 1ms min interval between strip.show()
    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
    [ledBar.cpp]
2025-11-28 refactor: Move VESC communication to dedicated FreeRTOS task on Core 0
    - Created src/vesc_task.cpp/h to handle VESC UART async
    - Defined public VescData struct to expose telemetry safely
    - Removed blocking GetVESCValues from main loop
    - Updated motor, log, datalog, and webserver to use thread-safe getVescData()
    - Fixed private struct access issues by copying data
    - Updated mocks and added test/datatypes.h for native
    [battery.cpp, datalog.cpp, log.cpp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]
2025-11-28 fix: Resolve LED corruption ('matsch') issues
    - Refactored ledBar logic to use uint32_t colors instead of Strings to prevent heap fragmentation and stack usage
    - Increased VESC task stack size from 4096 to 8192 bytes to prevent overflow during concurrent LED updates
    - Removed blocking String parsing from critical LED control paths"
    [ledBar.cpp, vesc_task.cpp]
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2025-11-29 LEDBar fix
    educe LED bus traffic by batching updates" -m "Introduce 'immediateShow' parameter to setBar functions to allow deferring strip.show().
    Batch updates when reverting from lamp/flash mode: update speed/standby first (no show), then battery (with show).
    This reduces the number of WS2812 transactions by 50% in critical moments, reducing the risk of WiFi interference ('LED mush')
    [ledBar.cpp, ledLamp.cpp, main.cpp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]
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2025-12-01 test VESC Bridge
    DRAM is too big!
    [api-specification.yaml, vesc_task.cpp, webserver.cpp]
2025-12-01 Revert "test VESC Bridge"
    This reverts commit 1319ba80f0b5e6e351e83cb501d9251544aaa5db.
    [api-specification.yaml, vesc_task.cpp, webserver.cpp]
2025-12-01 add reverse speed
    https://github.com/BubTec/DPVControl/issues/41
    [button.cpp, ledBar.cpp, motor.cpp]
2025-12-01 fix reverse standby lock
    [button.cpp, motor.cpp]
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

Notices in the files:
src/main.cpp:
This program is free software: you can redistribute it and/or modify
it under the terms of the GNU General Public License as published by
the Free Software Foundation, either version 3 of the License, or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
